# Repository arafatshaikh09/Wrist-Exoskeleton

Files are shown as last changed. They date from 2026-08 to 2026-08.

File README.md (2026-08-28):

# Design and Development of a Unilateral Wrist Exoskeleton for Home-Based Stroke Rehabilitation

This repository contains the mechanical designs, kinematic models, and control architecture for a lightweight, unilateral, tendon-driven wrist exoskeleton. Designed specifically for unmonitored home-based stroke rehabilitation, the system targets the clinical condition of "wrist drop" by actively assisting fine motor movements without relying on heavy, rigid physical hinges.

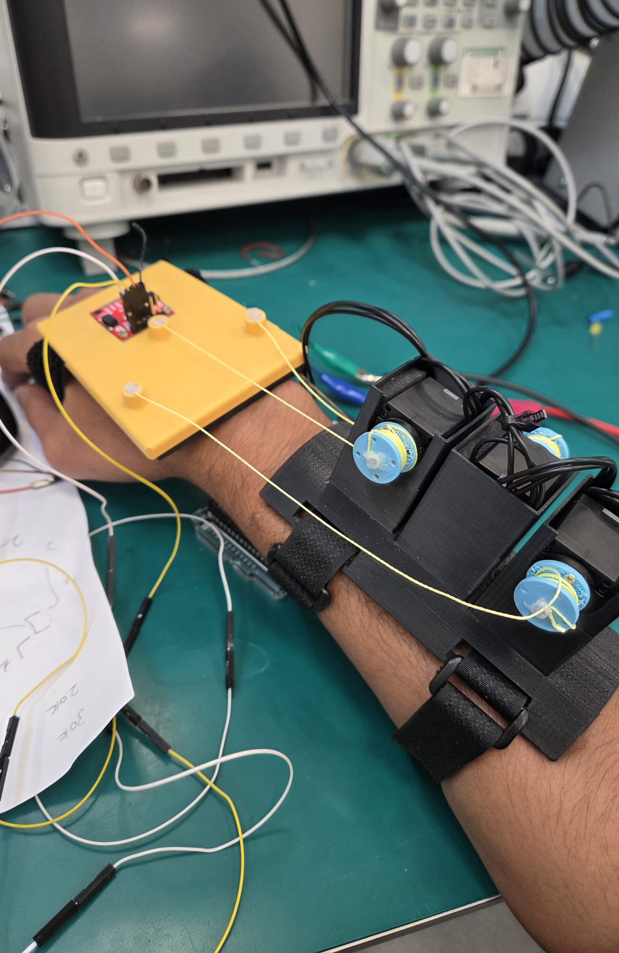
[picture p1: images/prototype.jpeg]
Physical Prototype


*The assembled 3D-printed prototype*

---

## System Architecture

The device eliminates the bulky mechanisms found in traditional clinical robots by utilizing a remote tendon-driven parallel actuation strategy. The heavy electromechanical hardware is shifted proximally to the forearm, reducing the distal weight the patient must manipulate.

- **Mechanical Design:** A 3D-printed modular forearm anchor cuff and a "floating" dorsal hand plate, modeled in SolidWorks.
- **Actuation:** A 3-tendon parallel mechanism utilizing high-strength fishing line, driven by three Dynamixel XC330-M288-T smart servomotors.
- **Degrees of Freedom:** 2-DOF control covering flexion/extension and radial/ulnar deviation.
- **Embedded Electronics:** A dual-microcontroller architecture utilizing an Arduino MKR Zero for high-speed sensor data acquisition and an Arduino Mega R3 for deterministic motor control.
- **Spatial Tracking:** A FANSPARK BMI-270 Inertial Measurement Unit (IMU) mounted on the end-effector provides absolute spatial orientation tracking.

---

## Kinematic Modeling & Control

To ensure absolute safety for independent home use, the exoskeleton avoids volatile real-time sensor feedback loops (such as sEMG) and instead relies on mathematically deterministic trajectory control.

- **MATLAB Validation:** Robust inverse and forward kinematic formulations were derived and heavily validated via MATLAB.
- **Trajectory Planning:** The mathematical models successfully map target therapeutic clinical wrist angles ($\pm 30^\circ$) directly to precise linear motor spooling distances ($\Delta L$).
- **Continuous Passive Motion (CPM):** The system executes smooth, pre-calculated rehabilitative trajectories, ensuring the patient's wrist is guided safely without mechanical singularities.

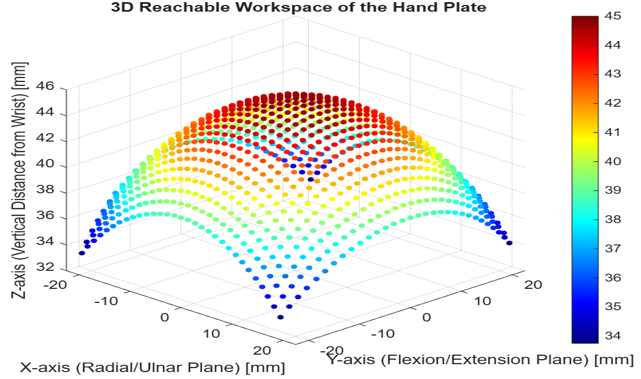
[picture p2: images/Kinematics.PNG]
Kinematic Validation


*MATLAB simulation of the 3D reachable workspace and inverse kinematics validation*

---

## Future Work

The current prototype successfully proves the mathematical viability of the 3-tendon mechanism for CPM. Future development phases will focus on re-integrating a dense sensor network specifically Interlink FSR 400 force sensors and a multiplexed dual-IMU configuration to transition the control software from passive motion to a dynamic "Assist-as-Needed" admittance control loop.

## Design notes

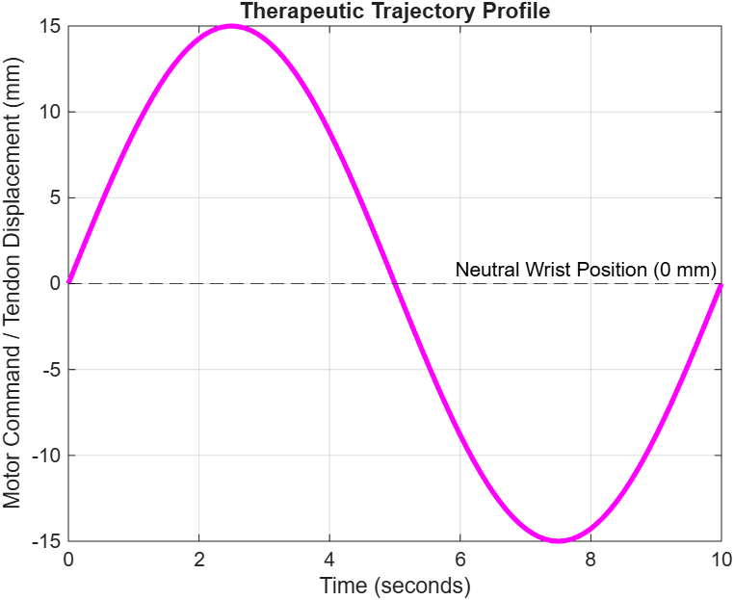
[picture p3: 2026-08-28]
MATLAB_Kinematics/Figure 3_ Therapeutic Trajectory Profile.png

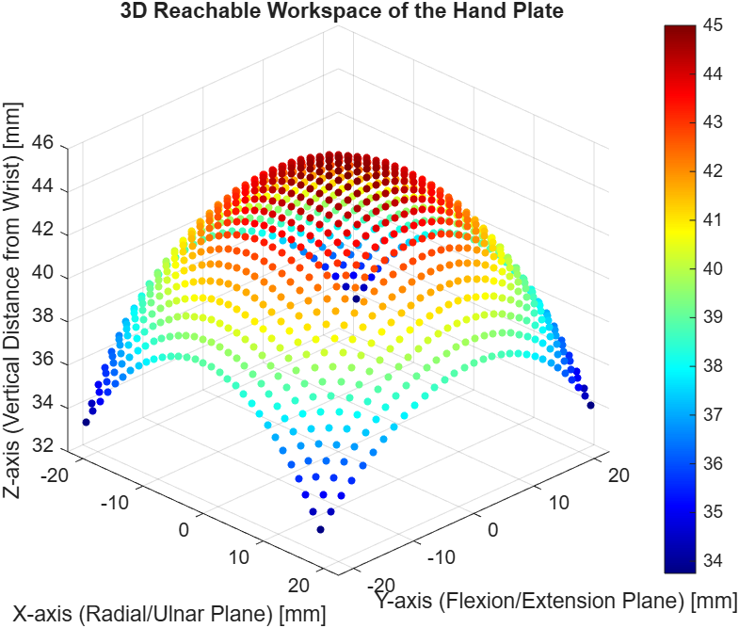
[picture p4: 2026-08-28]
MATLAB_Kinematics/exo1 (1).png

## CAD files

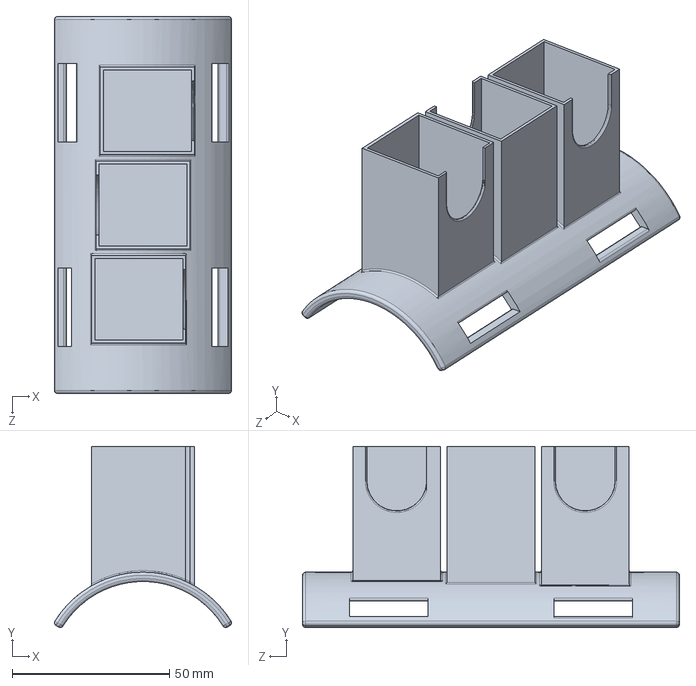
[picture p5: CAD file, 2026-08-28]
CAD_Models/forearmcuff_qtyx1ABS.SLDPRT
56.4 x 57.6 x 120.0 mm

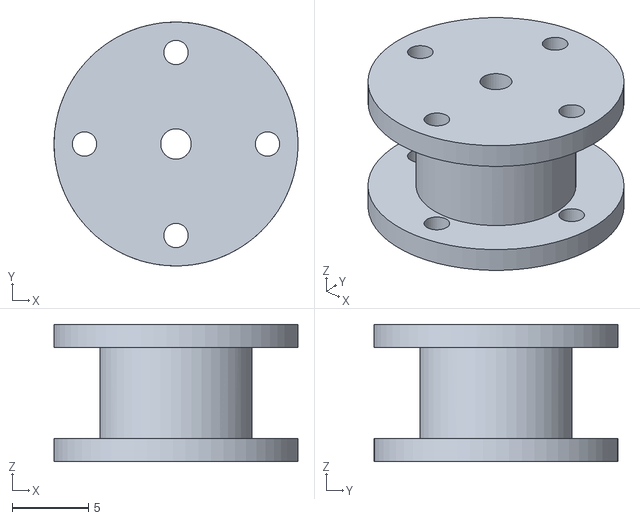
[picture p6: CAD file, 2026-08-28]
CAD_Models/spool_qtyx3.STL
16.0 x 16.0 x 9.00

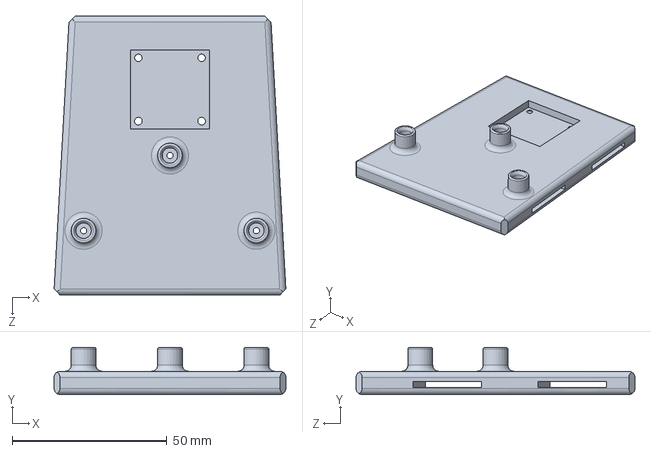
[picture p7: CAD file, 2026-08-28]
CAD_Models/Wrist plate_qtyx1ABS.SLDPRT
74.8 x 15.2 x 90.0 mm

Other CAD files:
CAD_Models/spool.SLDPRT
CAD_Models/Wrist plate_qtyx1ABS.STL
CAD_Models/forearmcuff_qtyx1ABS.STL

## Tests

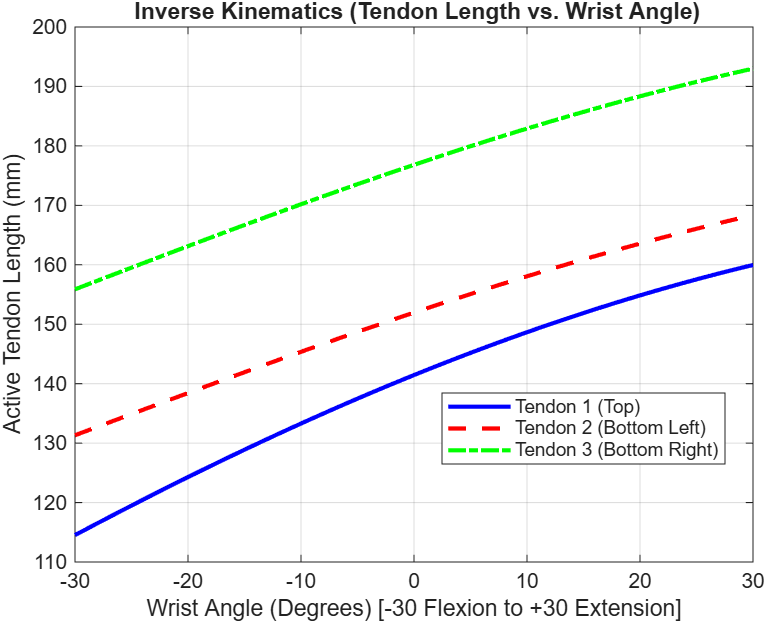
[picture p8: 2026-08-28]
MATLAB_Kinematics/Figure 2_ Inverse Kinematics Validation.png

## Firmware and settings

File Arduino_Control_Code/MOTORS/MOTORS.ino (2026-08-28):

#include <DynamixelShield.h>

const uint8_t MOTOR_1 = 1; // Top Extensor
const uint8_t MOTOR_2 = 2; // Middle (Right/Pinky side) -> INVERTED SPOOL
const uint8_t MOTOR_3 = 3; // Furthest (Left/Thumb side) -> STANDARD SPOOL

const float DXL_PROTOCOL_VERSION = 2.0;
DynamixelShield dxl;

const int CENTER_1 = 2300; 
const int CENTER_2 = 2048;
const int CENTER_3 = 2048;

void setup() {
  Serial.begin(115200); 
  Serial1.begin(9600);  

  dxl.begin(57600);
  dxl.setPortProtocolVersion(DXL_PROTOCOL_VERSION);

  uint8_t motor_ids[] = {MOTOR_1, MOTOR_2, MOTOR_3};
  for(int i = 0; i < 3; i++) {
    if(dxl.ping(motor_ids[i])) {
      dxl.torqueOff(motor_ids[i]);
      dxl.setOperatingMode(motor_ids[i], OP_POSITION);
      dxl.torqueOn(motor_ids[i]);
    }
  }
  
  dxl.setGoalPosition(MOTOR_1, CENTER_1);
  dxl.setGoalPosition(MOTOR_2, CENTER_2);
  dxl.setGoalPosition(MOTOR_3, CENTER_3);
  Serial.println("Mega Ready. Max Limits & Corrected Thumb/Pinky Logic Active.");
}

void loop() {
  if (Serial1.available() > 0) {
    char command = Serial1.read();

    if (command == 'E') {
      // EXTENSION: Max pull on top motor, max loosen on bottom motors
      dxl.setGoalPosition(MOTOR_1, 4000); // M1 Max Pull (Standard)
      dxl.setGoalPosition(MOTOR_2, 4000); // M2 Max Loosen (Inverted)
      dxl.setGoalPosition(MOTOR_3, 100);  // M3 Max Loosen (Standard)
    } 
    else if (command == 'F') {
      // FLEXION: Loosen top motor, max pull on bottom motors
      dxl.setGoalPosition(MOTOR_1, 100);  // M1 Max Loosen 
      dxl.setGoalPosition(MOTOR_2, 100);  // M2 Max Pull (Inverted)
      dxl.setGoalPosition(MOTOR_3, 4000); // M3 Max Pull (Standard)
    } 
    else if (command == 'A') {
      // THUMB SIDE (Radial Deviation): Pull M3, Loosen M2
      dxl.setGoalPosition(MOTOR_1, CENTER_1); 
      dxl.setGoalPosition(MOTOR_2, 4000); // M2 Loosens (Inverted High)
      dxl.setGoalPosition(MOTOR_3, 4000); // M3 Pulls (Standard High)
    }
    else if (command == 'D') {
      // PINKY SIDE (Ulnar Deviation): Pull M2, Loosen M3
      dxl.setGoalPosition(MOTOR_1, CENTER_1); 
      dxl.setGoalPosition(MOTOR_2, 100);  // M2 Pulls (Inverted Low)
      dxl.setGoalPosition(MOTOR_3, 100);  // M3 Loosens (Standard Low)
    }
    else if (command == 'C') {
      // CENTER
      dxl.setGoalPosition(MOTOR_1, CENTER_1);
      dxl.setGoalPosition(MOTOR_2, CENTER_2);
      dxl.setGoalPosition(MOTOR_3, CENTER_3);
    }
  }
}

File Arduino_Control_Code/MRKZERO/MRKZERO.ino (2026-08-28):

#include <Wire.h>
#include "SparkFun_BMI270_Arduino_Library.h"

BMI270 imu;
float smoothPitch = 0;
float smoothYaw = 0; // Replaces 'Roll' to track flat left/right movement
unsigned long lastTime = 0;

uint8_t i2cAddress = BMI2_I2C_PRIM_ADDR; // 0x68

void setup() {
    Serial.begin(115200);
    Serial1.begin(9600);
    Wire.begin();
    
    while(imu.beginI2C(i2cAddress) != BMI2_OK) {
        Serial.println("Error: BMI270 not connected!");
        delay(1000);
    }
    Serial.println("BMI270 connected! Gyro Yaw Tracking Active.");
    lastTime = millis();
}

void loop() {
  imu.getSensorData();

  // 1. Calculate time passed (dt) for the Gyroscope
  unsigned long currentTime = millis();
  float dt = (currentTime - lastTime) / 1000.0;
  lastTime = currentTime;

  // 2. PITCH (Up/Down) using Accelerometer
  float ax = imu.data.accelX;
  float ay = imu.data.accelY;
  float az = imu.data.accelZ;
  float rawPitch = atan2(-ax, sqrt(ay * ay + az * az)) * 180.0 / PI;
  smoothPitch = (0.2 * rawPitch) + (0.8 * smoothPitch);

  // 3. YAW (Left/Right) using Z-Axis Gyroscope
  float gz = imu.data.gyroZ;
  if (abs(gz) > 2.0) { 
      smoothYaw += (gz * dt); // Integrate rotation into position
  } else {
      smoothYaw = smoothYaw * 0.95; // Auto-center when stopped
  }

  Serial.print("Pitch: "); Serial.print(smoothPitch, 1);
  Serial.print(" | Yaw: "); Serial.print(smoothYaw, 1);

  // --- 4-WAY EXOSKELETON LOGIC ---
  if (smoothPitch > 15.0) {
    Serial1.write('E'); 
    Serial.println(" -> EXTEND");
  } 
  else if (smoothPitch < -15.0) {
    Serial1.write('F'); 
    Serial.println(" -> FLEX");
  } 
  else if (smoothYaw > 15.0) {
    Serial1.write('A'); // Abduction (Thumb/Radial)
    Serial.println(" -> RADIAL TILT (Left)");
  }
  else if (smoothYaw < -15.0) {
    Serial1.write('D'); // Adduction (Pinky/Ulnar)
    Serial.println(" -> ULNAR TILT (Right)");
  }
  else {
    Serial1.write('C'); 
    Serial.println(" -> CENTER");
  }

  delay(50);
}

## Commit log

2026-08-28 Added CAD/3D print files
    [Wrist plate_qtyx1ABS.SLDPRT, Wrist plate_qtyx1ABS.STL, forearmcuff_qtyx1ABS.SLDPRT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]
2026-08-28 Matlab Kinematics
